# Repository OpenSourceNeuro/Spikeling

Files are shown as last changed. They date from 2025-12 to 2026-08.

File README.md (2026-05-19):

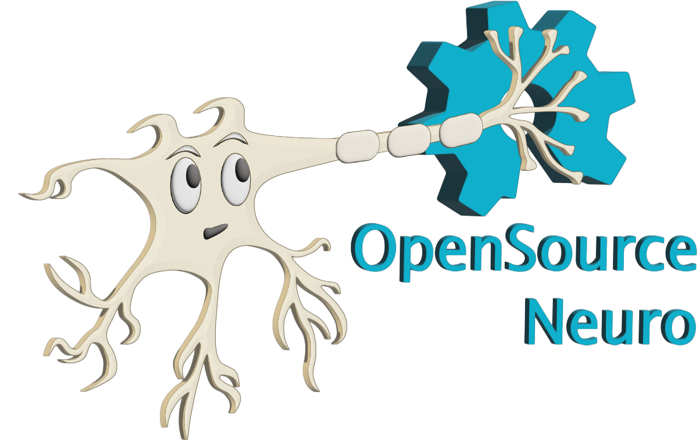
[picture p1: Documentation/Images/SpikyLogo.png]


<div align="center">

# **Spikeling v3**

### **An open-source hardware + software platform for neuroscience teaching and outreach:**  

A hands-on “artificial spiking neuron” running the **Izhikevich model** on an **ESP32**, with a desktop **GUI** for visualization, interaction, and data export.

<p>
  <a href="LICENSE.txt">
    
  </a>
  <a href="https://github.com/OpenSourceNeuro/Spikeling/releases">
    
  </a>
  <a href="https://opensourceneuro.github.io/Spikeling/Firmware/Spikeling_V3">
  
</a>
  <a href="https://opensourceneuro.github.io/Spikeling/">
    
  </a>
</p>

<p align="right">
  developed by M.J.Y. Zimmermann<br>
  maintained by P. Rignanese & A. Koumoundourou<br>
  based on an original idea by T. Baden
</p>

</div>

This project is licensed under the [GNU General Public License v3.0](https://www.gnu.org/licenses/gpl-3.0.en.html)
<br>
The hardware is licensed under the [ CERN-OHL-S-2.0](https://gitlab.com/ohwr/project/cernohl/-/wikis/uploads/b88fd806c337866bff655f2506f23d37/cern_ohl_s_v2_user_guide.txt)

## Contents

- [What is Spikeling?](#what-is-spikeling)
- [Spikeling in academia & outreach](#spikeling-in-academia--outreach)
- [A brief summary of Spikeling functions](#a-brief-summary-of-spikeling-functions)
  - [Neurophysiology](#neurophysiology)
  - [Data analysis](#data-analysis)
  - [Neuron generator](#neuron-generator)
  - [Stimulus generator](#stimulus-generator)
  - [Multi-recording & networking](#multi-recording--networking-multi-unit-experiments)
  - [Fluorescence imaging simulation](#fluorescence-imaging-simulation)
  - [Exercises](#exercises)
- [Documentation](#documentation)
- [Contributing](#contributing)
- [License](#license)

---

<br>

<div align="center">

## What is Spikeling?

<br>

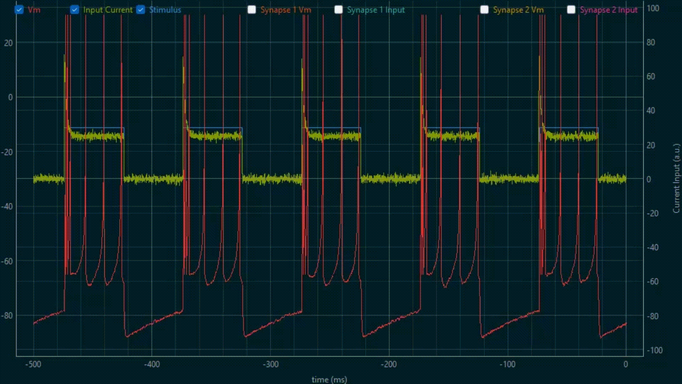
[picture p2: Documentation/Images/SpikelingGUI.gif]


<p style='text-align: justify;'>
  Spikeling is an open-source neuroscience education platform designed to make core neurophysiology concepts teachable through hands-on experimentation, even in settings where traditional wet-lab electrophysiology is impractical.
</p>

<p style='text-align: justify;'>
  In many degree programs, students learn about action potentials and synaptic signalling largely through lectures or static datasets because living preparations, microscopes, amplifiers, and specialist supervision do not scale well to large cohorts. Spikeling addresses this gap with a low-cost “in silico neuron” implemented in hardware.
</p>

<p style='text-align: justify;'>
  The device runs the computationally efficient and versatile <strong>Izhikevich spiking neuron model</strong> in real time on an ESP32-based microcontroller, providing electrophysiology-style interaction: controlled stimulation, measurable membrane-voltage dynamics, spike output, and parameter manipulation to explore firing regimes, adaptation, and input integration.
</p>

<p style='text-align: justify;'>
  A dedicated <strong>cross-platform desktop GUI</strong> supports real-time plotting, experiment control, and recording/export to standard formats—enabling teaching modules that extend beyond neurophysiology into protocol design, data collection, analysis pipelines, and model-based reasoning.
</p>

</div>

<br>

<div align="center">

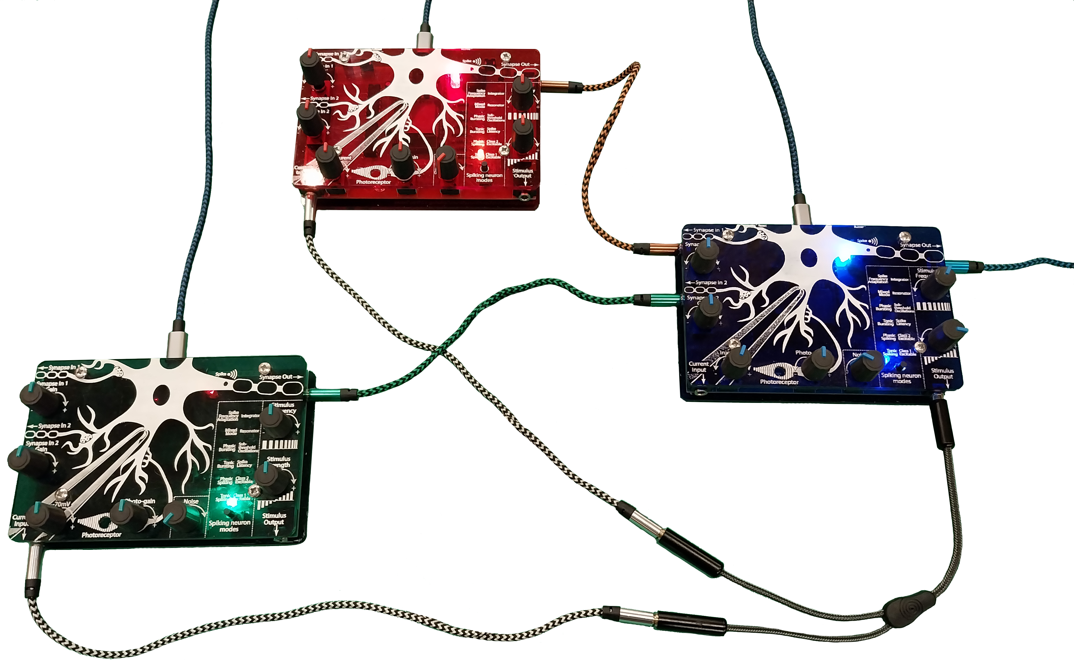
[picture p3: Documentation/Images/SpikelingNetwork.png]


<h6 align="center">Two spikeling units (red and green), that are synchronously stimulated (white cables), synapse with a third unit (blue).</h6>

</div>

---

<br>

<div align="center">

## Spikeling in academia & outreach

<br>

<p style='text-align: justify;'>
  The spikeling project emerged from local needs to teach neuroscience class modules for direct interaction with <strong>neuron physiology, data analysis, fluorescence imaging, protocol design, etc.</strong>
</p>

<p style='text-align: justify;'>
  The aim was to provide <strong>hands-on experience</strong> on how neurons encode information and how diverse variables modulates their activities, while engaging students with <strong>crucial aspects of data collection, experimental limitations, methodology and statistical analysis.</strong>
</p>

<p style='text-align: justify;'>
  Spikeling is currently used in <strong>university teaching, computational neuroscience training, and outreach events</strong>. It is intentionally <strong>open (hardware + firmware + software)</strong> so educators can customize activities for their courses and contribute back to a shared pool of teaching material.
</p>

<p align="center">
  Spikeling workshop — students using the device in South Africa (2022)
</p>

<table>
  <tr>
    <td width="33%">
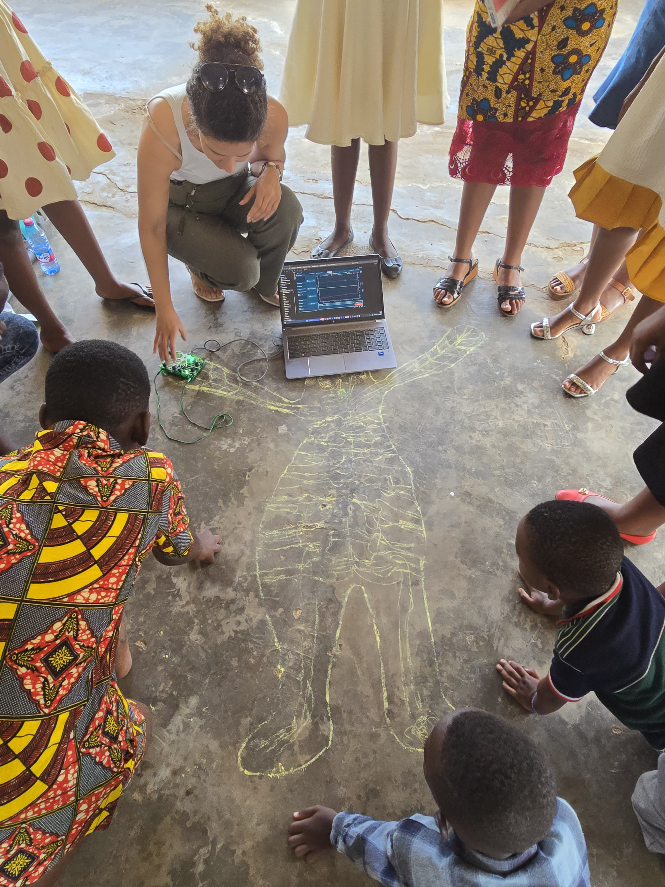
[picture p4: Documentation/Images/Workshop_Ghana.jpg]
      <br>
      <sub><b>Outreach demonstration of neuron activities to primary school student in Ghana (2025)</b></sub>
    </td>
    <td width="33%">
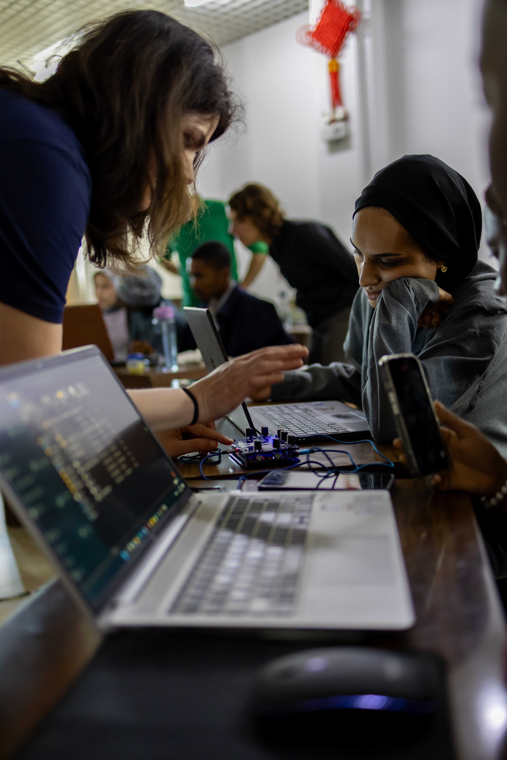
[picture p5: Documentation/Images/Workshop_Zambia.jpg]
      <br>
      <sub><b>Hands-on electrophysiology-style experiments in Zambia (2025)</b></sub>
    </td>
    <td width="33%">
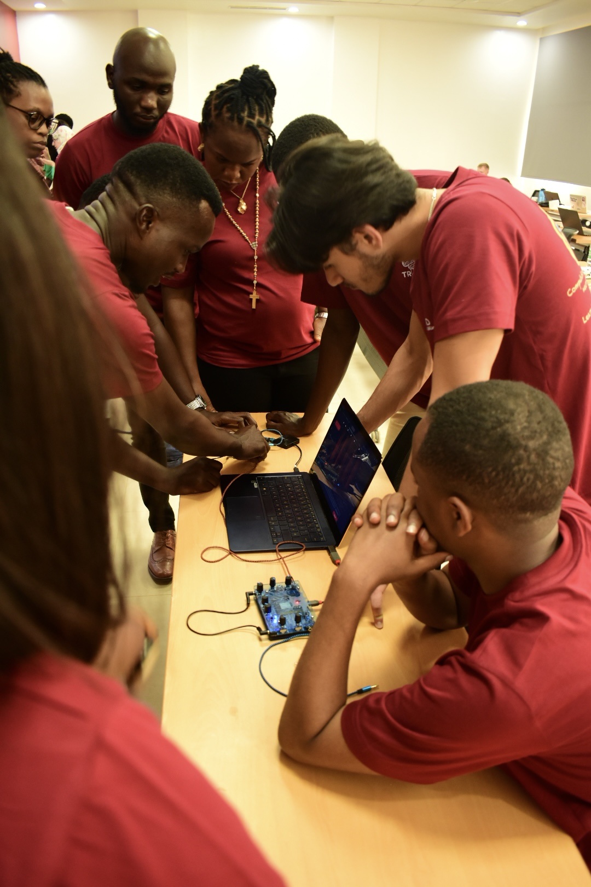
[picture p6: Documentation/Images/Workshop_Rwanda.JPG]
      <br>
      <sub><b>Small-group protocol design & parameter exploration in Rwanda (2024)</b></sub>
    </td>
  </tr>

</table>

</div>

***

<br>

<div align="center">

## A brief summary of Spikeling functions

<br>

<h3 align="left"> Neurophysiology:</h3></p>

<p style='text-align: justify;'>
  Spikeling implements the <strong>Izhikevich model</strong>, which “reproduces spiking and bursting behaviour of known type of cortical neurons. The model combines the <strong>biologically plausibility of Hodgkin-Huxley-type dynamics</strong> and the <strong>computational efficiency of integrate-and-fire neurons</strong>” <a href="https://ieeexplore.ieee.org/document/1257420"> E. M. Izhikevich, "Simple model of spiking neurons, 2003"</a>.
  This makes it well-suited for teaching as learners can move quickly between <strong>hypothesis → stimulation → observation → interpretation</strong>.
</p>

<p style='text-align: justify;'>
  Neurophysiology concepts are taught through electrophysiology-style interaction: students apply controlled inputs and directly observe membrane-voltage dynamics,
  thresholding, spike generation, and adaptation. This supports practical teaching objectives such as protocol design, parameter sensitivity, and reproducible experimentation.
</p>

<ul align="left">
  <li>
    <b>Patch-clamp style stimulation (current injection):</b>
    A simulated patch-clamp interface allows students to inject controlled current steps and waveforms.
    Learners can vary <b>amplitude</b>, <b>duration</b>, and <b>timing</b> to explore excitability, threshold, refractory effects, and spike-frequency adaptation.
  </li>

  <li>
    <b>Photo-sensitive input (photodiode / “photoreceptor”):</b>
    Spikeling includes a photodiode input that mimics sensory-driven current input.
    Students can test simple stimuli (e.g., flashlight pulses) and progress to controlled protocols using an external LED driven via the stimulus port
    (frequency/intensity). Advanced discussions can include response dynamics such as effective decay/recovery behaviour under repeated stimulation.
  </li>

  <li>
    <b>Synapses and networks (dendrites + axon):</b>
    Each unit provides <b>two dendritic inputs</b> with gain and polarity control (supporting excitatory and inhibitory effects) and <b>one axonal spike output</b>.
    This enables multi-unit experiments on coincidence detection, inhibition-driven gating, synchrony, and simple network motifs.
    Auxiliary units can be stimulated synchronously to keep network experiments controlled and reproducible.
  </li>
</ul>

<p style='text-align: justify;'>
  Together, these features let students reproduce classic teaching experiments:
  step-current response curves, threshold measurements, adaptation quantification, sensory-driven spiking, and basic synaptic/network computations—using the same device and workflow.
</p>

<br>

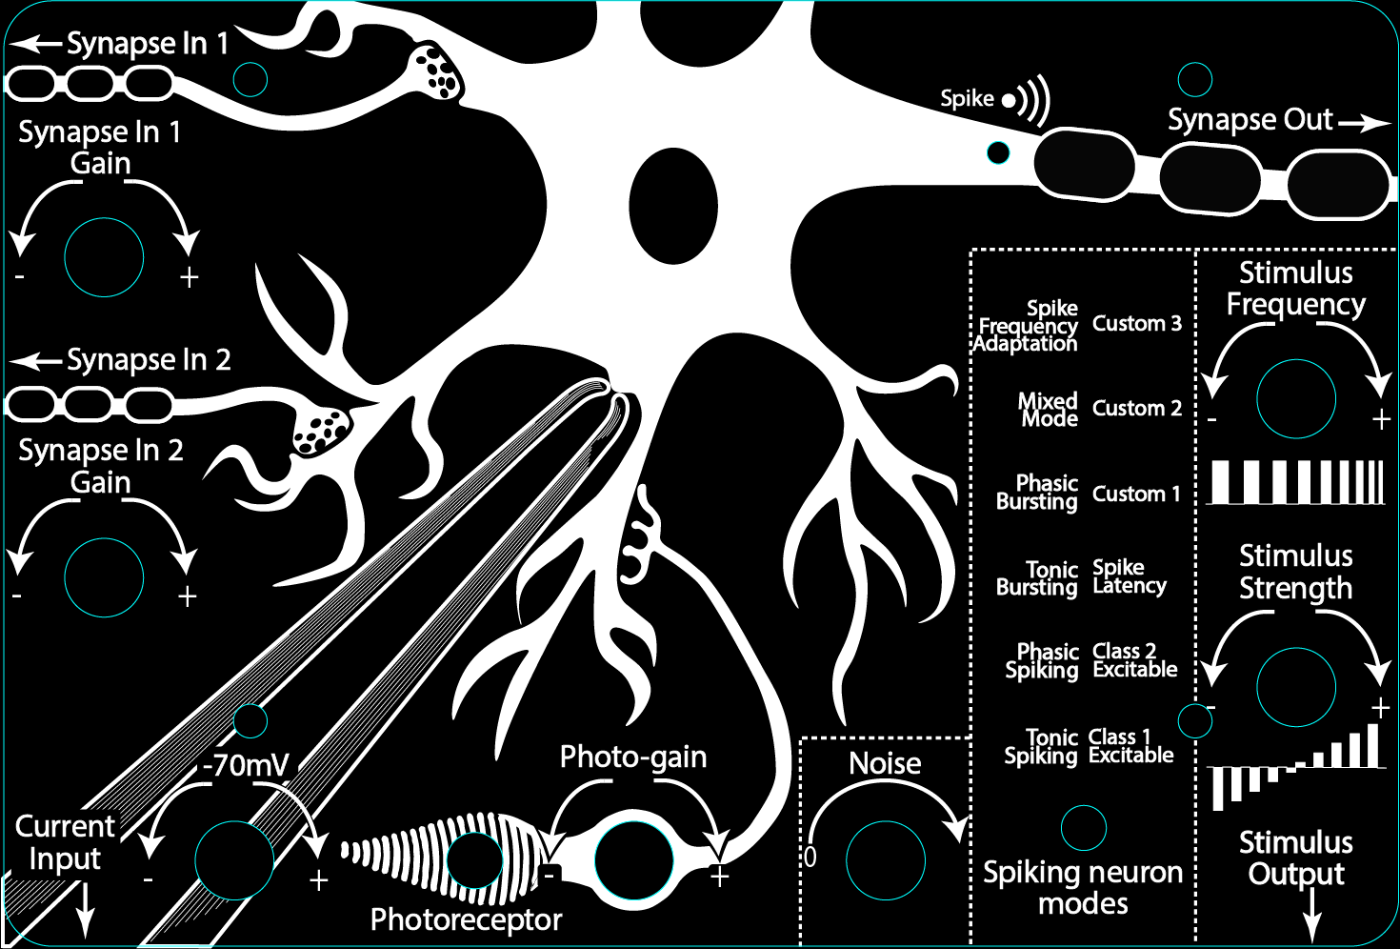
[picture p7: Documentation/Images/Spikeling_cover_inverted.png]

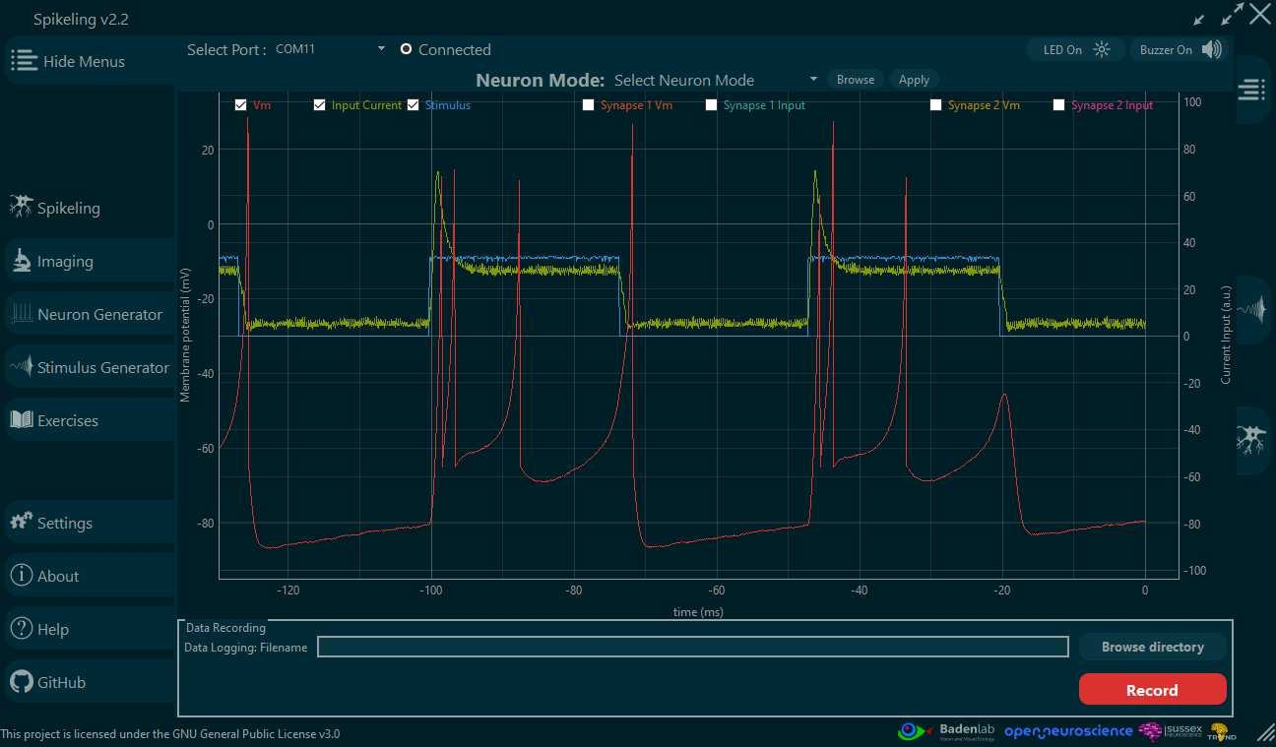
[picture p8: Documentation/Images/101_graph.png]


<h6 align="center">Left: Drawing on the acrylic cover of the Spikeling version 2.2, representing the controls knobs along with the input/ouput jacks.

Right: Spikeling GUI displaying the unit membrane voltage (red trace) while being light-stimulated by a controlled LED (blue trace) which generates input current (green trace).
</h6>

</div>

***

<div align="center">

<h3 align="left"> Data analysis</h3></p>

<p style='text-align: justify;'>
  Spikeling is designed to extend practical teaching beyond “watching spikes” into the full experimental workflow:
  <strong>recording</strong>, <strong>quality control</strong>, <strong>basic quantification</strong>, and <strong>export for reproducible analysis</strong>.
  This is particularly valuable in neuroscience curricula where students may have limited exposure to programming and data pipelines, yet are expected to interpret real experimental data.
</p>

<p style='text-align: justify;'>
Any data generated by Spikeling can be <strong>saved and exported</strong> for downstream analysis. The GUI also provides a lightweight,
<strong>built-in analysis</strong> layer that helps students validate recordings and immediately compute core measures such as spike detection and trial-averaged responses.
This supports in-class demonstrations, rapid iteration during labs, and structured home assignments.
</p>

<p style='text-align: justify;'>
  For advanced data analysis and basic statistics, <strong>python notebooks</strong> are provided to serve as template for the teaching staff. We are engage with the Spikeling community where users could share courses, exercises and data analysis scripts to be widely used in neuroscience and coding courses.
</p>

<ul align="left">
  <li>
    <b>Recording & export:</b>
    save time series (e.g., Vm, stimulus, derived currents, triggers) and export to standard formats (e.g., <b>CSV</b>) compatible with Python, MATLAB, R, Excel, etc.
  </li>
  <li>
    <b>Basic QC and annotation:</b>
    quickly verify signal integrity, confirm stimulus timing, and identify artefacts before committing to a full analysis workflow.
  </li>
  <li>
    <b>Spike detection and raster plots:</b>
    detect spikes from membrane-voltage traces and visualize them as rasters to introduce spike trains, variability, and stimulus-locked responses.
  </li>
  <li>
    <b>Trial alignment, looping, and averaging:</b>
    repeat identical stimulus protocols, align trials, and compute averaged traces and spike-rate summaries—making it easy to teach concepts like reliability,
    response variability, and signal-to-noise.
  </li>
  <li>
    <b>Bridge to coding modules:</b>
    provide exported datasets and template <b>Python notebooks</b> so teaching staff can scaffold progressively from GUI-based inspection to student-written analysis code.
  </li>
</ul>

<p style='text-align: justify;'>
  In short, Spikeling supports a gradual learning curve: students can begin with GUI-based inspection and built-in metrics,
  then transition to reproducible, script-based analysis using the exact same datasets—mirroring modern research practice.
</p>
<br>

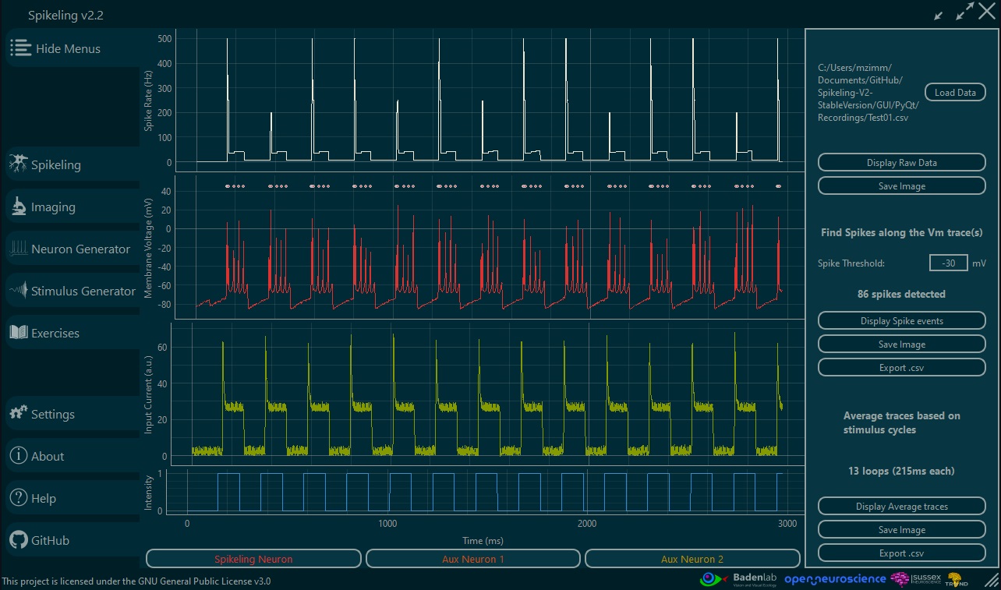
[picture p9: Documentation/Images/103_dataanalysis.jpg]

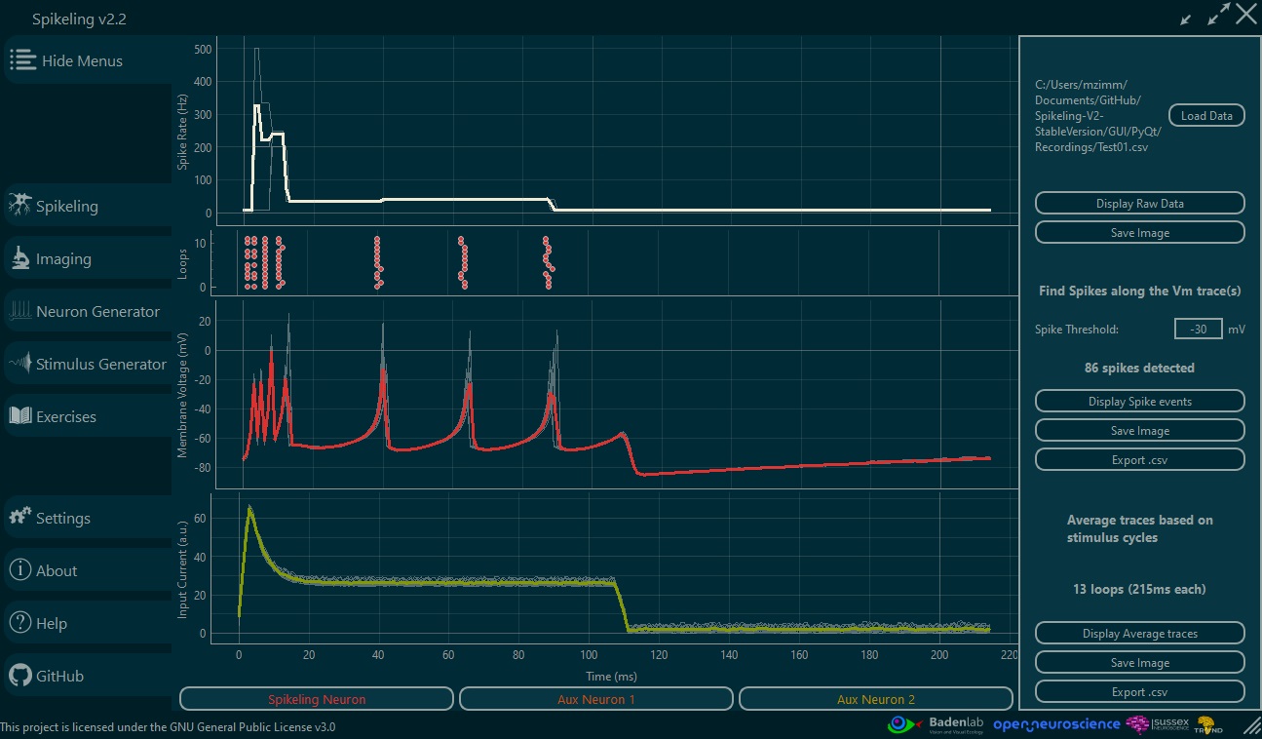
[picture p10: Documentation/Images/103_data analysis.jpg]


<h6 align="center">Left: Displayed data from the previous experiment (light stimulation) spikes are detected and ploted along the Vm trace (red). Right: Traces looped and averaged showing the spike rate (white), the raster plot (red dots), the averaged Vm recording (red) and the averaged input current (green)</h6>

</div>

***

<div align="center">

<h3 align="left"> Neuron generator</h3></p>

<p style='text-align: justify;'>
  The <strong>Neuron Generator</strong> is an interactive space for exploring the Izhikevich model beyond “playing with a few knobs”.
  It is designed to help students connect <strong>model parameters</strong> to <strong>observable firing behaviours</strong> (e.g., tonic spiking, bursting, adaptation, rebound, irregular firing),
  and to build intuition for how different neurons can emerge from the same compact set of equations.
</p>

<p style='text-align: justify;'>
  In practice, the Neuron Generator lets learners rapidly prototype neuron “types” by adjusting Izhikevich parameters and immediately observing
  how the neuron responds to standardized stimuli. This encourages a scientific workflow: formulate a hypothesis (e.g., “increasing adaptation should reduce firing rate over time”),
  test it with controlled stimulation, then iterate.
</p>

<ul align="left">
  <li><b>Explore firing regimes:</b> interactively vary Izhikevich parameters and observe changes in excitability, thresholding, bursting, and adaptation.</li>
  <li><b>Compare neurons under identical protocols:</b> run the same stimulus recipe on multiple parameter sets to build mechanistic intuition.</li>
  <li><b>Create & share presets:</b> save custom neuron parameter sets for labs, assignments, or reproducible classroom demonstrations.</li>
  <li><b>Bridge theory and experiment:</b> connect equations/parameters to patch-clamp-style readouts (Vm traces, spike trains, firing-rate changes).</li>
</ul>

<br>

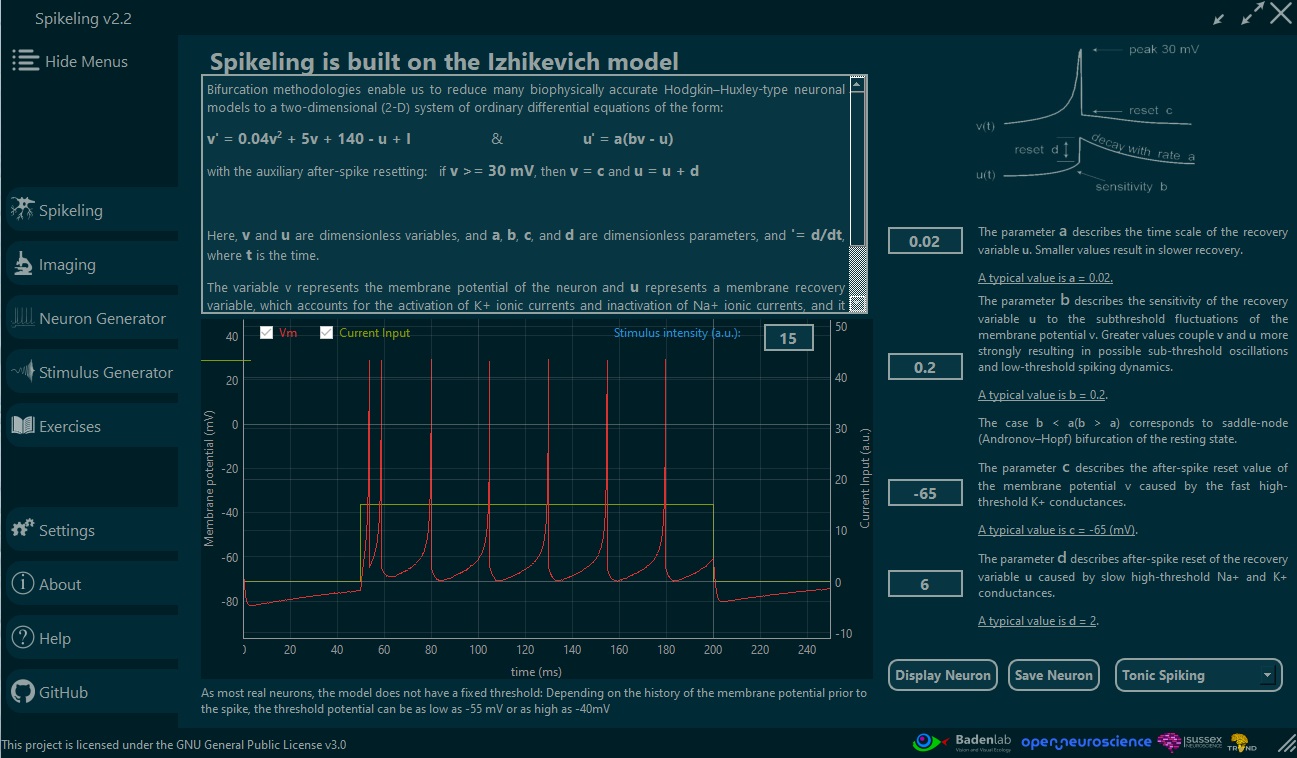
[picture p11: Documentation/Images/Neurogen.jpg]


<h6 align="center">GUI displaying the “Neuron Generator” page where users can appreciate the model underlying Spikeling activity and from which they can generate unique neuron to further run on Spikeling.</h6>

</div>

***

<div align="center">

<h3 align="left">Stimulus generator:</h3>

<p style='text-align: justify;'>
  Spikeling includes a dedicated <strong>Stimulus Generator</strong> to teach one of the most important (and often under-taught) parts of experimental neuroscience:
  <strong>protocol design</strong>. While Spikeling board only has a simple repeated square-wave stimulus (useful for classic current-step experiments and LED/light stimulation),
  the Stimulus Generator encourages students to move beyond “turning knobs” and instead design inputs that directly test experimental hypotheses.
</p>

<p style='text-align: justify;'>
  Users can create and iterate custom stimuli—such as <strong>step families</strong>, <strong>sinusoids</strong>, <strong>chirps</strong>, <strong>pulse trains</strong>, and <strong>binary/noise-like</strong> sequences—
  then apply them to current injection or light stimulation. A built-in <strong>stimulus preview</strong> allows learners to verify waveform timing, amplitude, and repetition structure
  <em>before</em> running an experiment, reinforcing good practice around sanity checks and reproducibility.
</p>

<ul align="left">
  <li><b>From standard to custom protocols:</b> start with square pulses and progress to structured waveforms used in electrophysiology and systems neuroscience.</li>
  <li><b>Preview before running:</b> confirm duration, inter-stimulus intervals, amplitude scaling, and repetition count to avoid protocol errors.</li>
  <li><b>Reproducible experimentation:</b> define explicit parameters to enable trial averaging and fair comparisons across neuron modes or conditions.</li>
  <li><b>Hypothesis-driven design:</b> link stimulus structure to questions like threshold, adaptation time constants, resonance, and response reliability under noise.</li>
</ul>

<br>

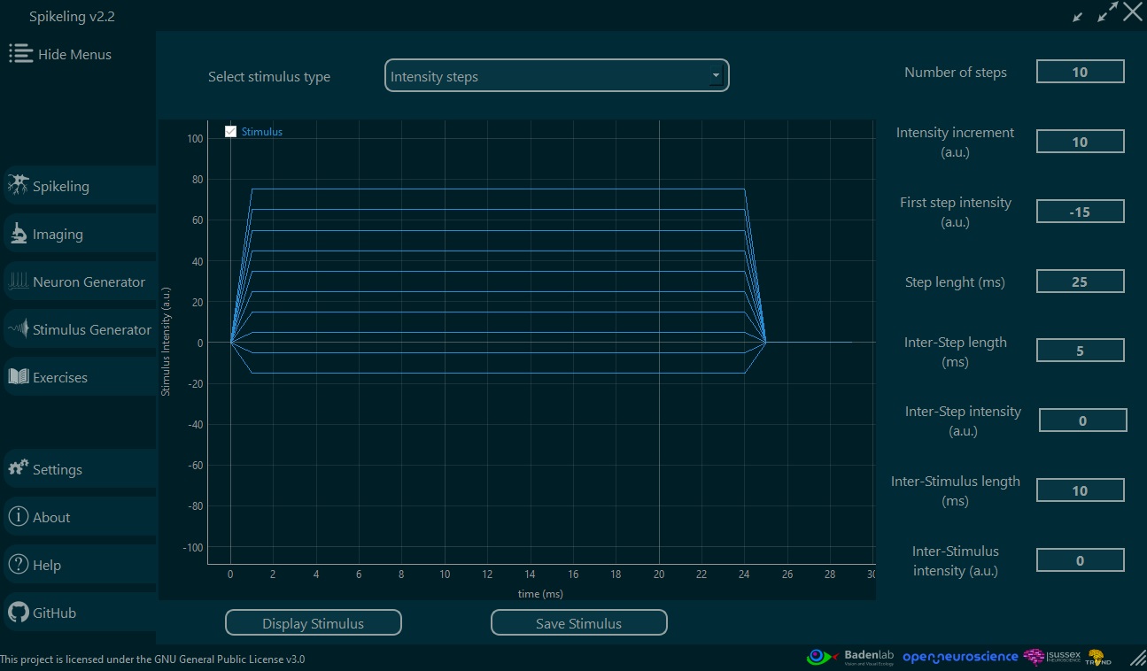
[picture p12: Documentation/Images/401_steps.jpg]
  
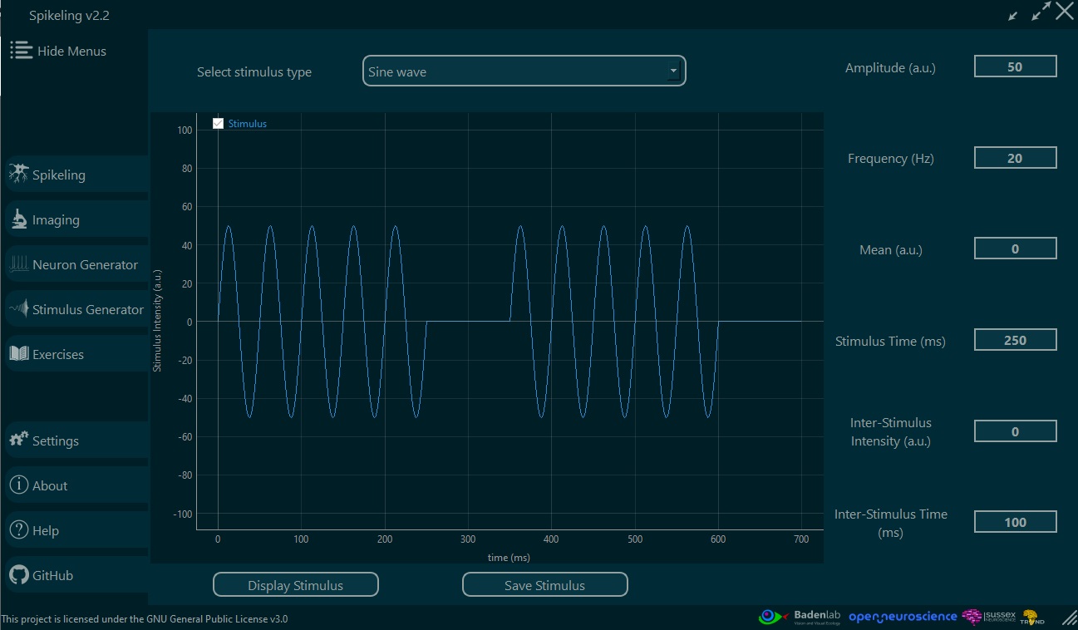
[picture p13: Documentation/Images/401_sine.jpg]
  

  <h6 align="center">
    Stimulus Generator examples (with preview). Left: classic electrophysiology-style step family (10 steps, 10 a.u. increment, 25 ms per step, 5 ms rest at 0 a.u.).
    Right: sine-wave stimulus (50 a.u. amplitude, 20 Hz, 250 ms duration, 100 ms rest at 0 a.u.).
  </h6>

</div>

***

<div align="center">

<h3 align="left">Multi-recording & networking (multi-unit experiments):</h3>

<p style='text-align: justify;'>
  A key strength of Spikeling is that it can be scaled from a single “neuron” demo to <strong>small, interpretable networks</strong>.
  Each unit provides an <strong>axonal spike output</strong> and two <strong>dendritic (synaptic) inputs</strong>, enabling multiple Spikelings to be physically connected
  and studied as a functional circuit. This makes it possible to teach network-level computation using the same workflow as single-cell experiments:
  controlled stimulation, direct observation, and quantitative comparison.
</p>

<p style='text-align: justify;'>
  Importantly, each synaptic input can be configured as <strong>excitatory or inhibitory</strong> (via the synaptic gain control), allowing learners to explore
  how the <strong>sign</strong> and <strong>strength</strong> of coupling shapes membrane dynamics and spiking output. The GUI supports <strong>multi-recording</strong> by plotting and saving,
  in the same session, the activity of the main unit alongside the incoming synaptic streams (and, when available, the associated presynaptic signals),
  which is essential for teaching causality, timing, and interaction effects.
</p>

<ul align="left">
  <li><b>Excitation vs inhibition:</b> set synaptic gain positive or negative to illustrate recruitment of spiking vs suppression/gating.</li>
  <li><b>Timing-dependent effects:</b> compare synchronous vs offset inputs to demonstrate coincidence detection and integration windows.</li>
  <li><b>Simple circuit motifs:</b> build and test canonical motifs (feedforward excitation, inhibitory gating, E/I balance, two-input integration).</li>
  <li><b>Multi-channel recording:</b> visualize and export multiple traces simultaneously (main Vm, stimulus, synaptic inputs, and optional partner activity) for downstream analysis.</li>
</ul>

<br>

<div>
  <!-- Rename/move these screenshots into your repo (recommended location: ./Documentation/Images/ ) -->
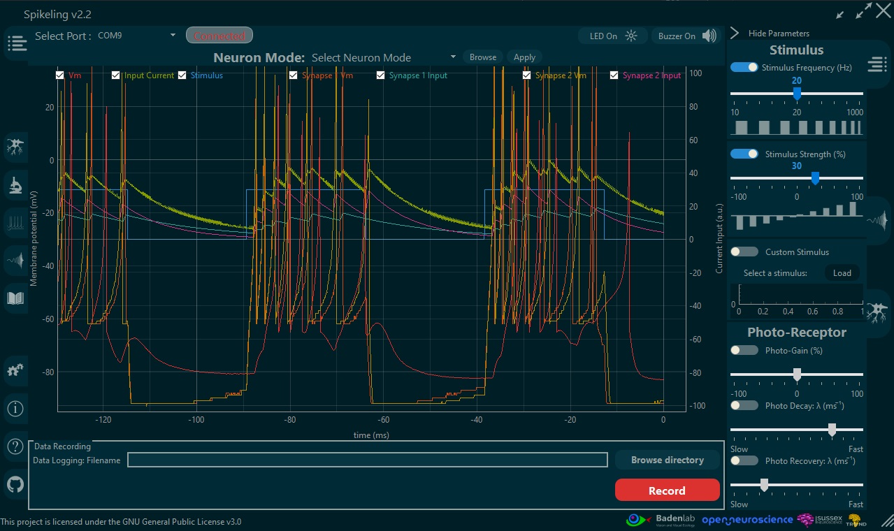
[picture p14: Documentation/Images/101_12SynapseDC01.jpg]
  
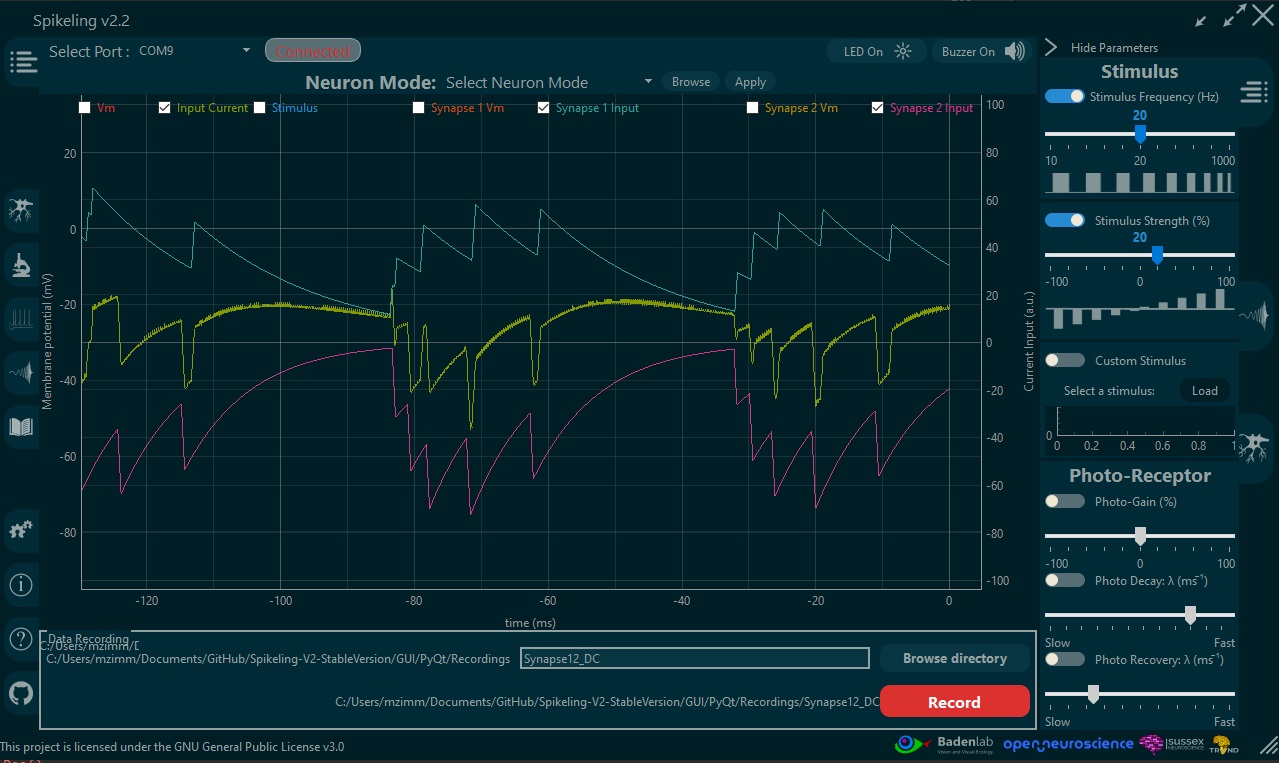
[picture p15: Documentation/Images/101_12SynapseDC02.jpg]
  

  <h6 align="center">
    Multi-unit / synaptic networking example recorded in the GUI.
    Left: <b>excitatory</b> synaptic drive increases firing probability and can recruit spikes in the postsynaptic neuron.
    Right: <b>inhibitory</b> synaptic drive suppresses spiking and gates responses despite ongoing stimulation.
    In both cases, synaptic streams and membrane activity are visualised together, enabling direct comparison of circuit configurations.
  </h6>

</div>

---

<div align="center">

<h3 align="left">Fluorescence imaging simulation:</h3>

<p style='text-align: justify;'>
  Because Spikeling produces real-time <strong>membrane-voltage</strong> traces (and therefore a known spike train), it provides an ideal “ground truth” signal
  to introduce students to <strong>calcium imaging</strong> and the relationship between spikes, intracellular calcium dynamics, and measured fluorescence.
  The GUI can transform spiking activity into a simulated <strong>calcium concentration transient</strong>, and then into a simulated <strong>fluorescence signal</strong>,
  allowing learners to explore how imaging readouts relate to the underlying electrophysiology.
</p>

<p style='text-align: justify;'>
  Students can manipulate variables that mirror real experimental constraints—both on the acquisition side (e.g., <strong>frame rate</strong>, <strong>detector gain</strong>, <strong>noise level</strong>)
  and on the biophysical/indicator side (e.g., <strong>baseline calcium</strong>, <strong>decay time constant</strong>, <strong>spike-triggered calcium increment</strong>,
  <strong>indicator affinity / dissociation constant</strong>, <strong>brightness</strong>, and <strong>photobleaching-like effects</strong>).
  This helps learners understand why calcium traces are not a direct copy of spikes, and why interpretation depends on both biology and measurement.
</p>

<p style='text-align: justify;'>
  For increased realism, the simulation can be switched from a <strong>linear</strong> fluorescence model to a <strong>non-linear saturating</strong> model,
  illustrating common limitations such as dynamic range, saturation at high activity, and the consequences for comparing firing rates across conditions.
</p>

<br>

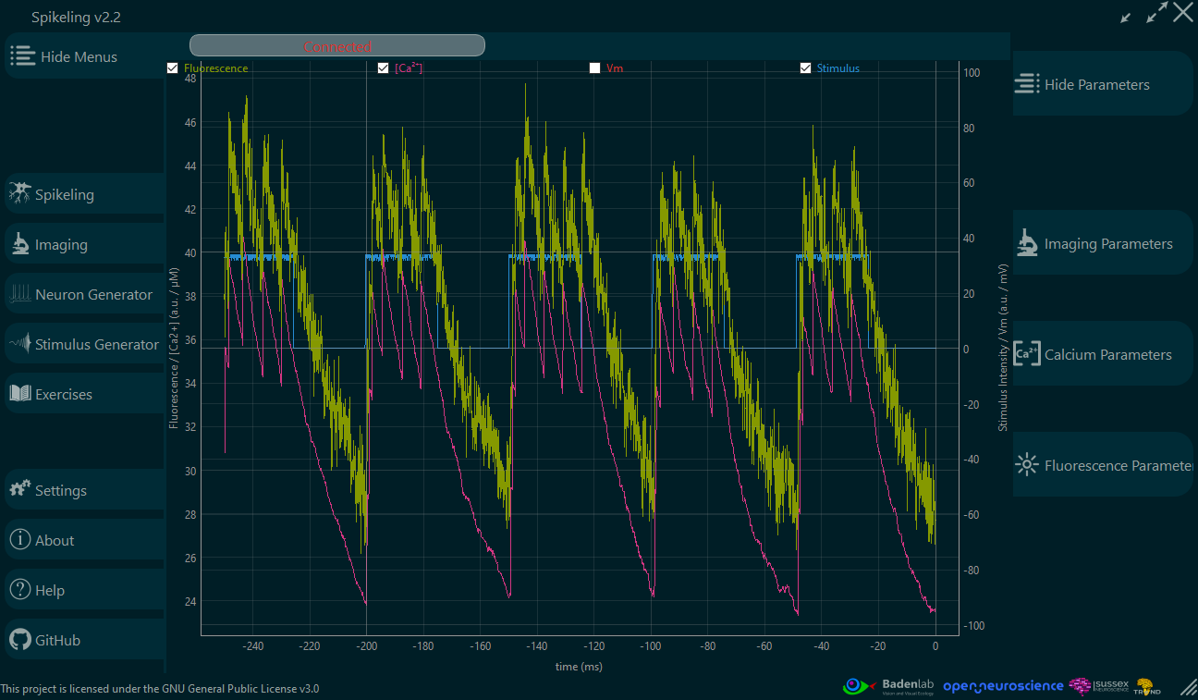
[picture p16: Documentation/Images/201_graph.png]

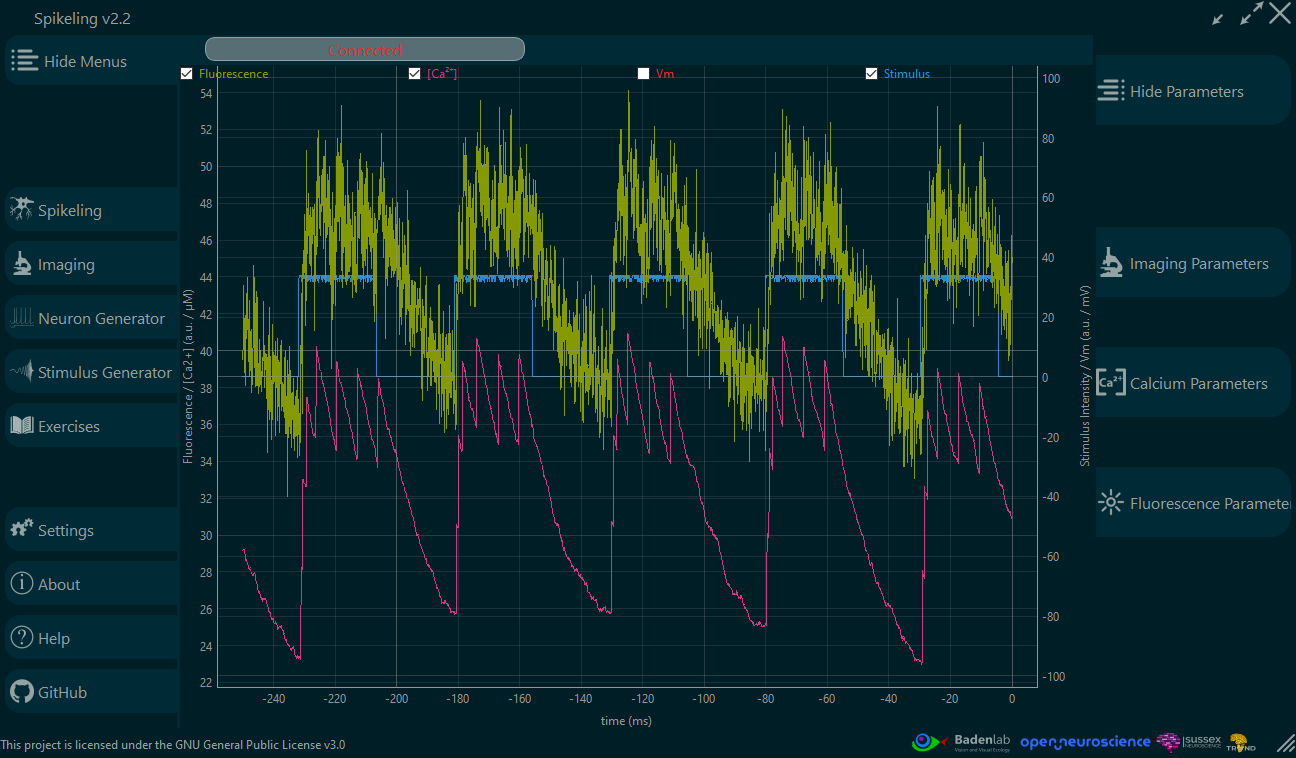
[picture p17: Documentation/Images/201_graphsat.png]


<h6 align="center">
  Imaging simulation in the GUI: linear (left) and saturating / non-linear (right) fluorescence models (green) generated from simulated calcium concentration dynamics (pink).
</h6>

<p style='text-align: justify;'>
  The objective is to familiarise students with the type of data they will encounter in modern systems and circuit neuroscience:
  signals that are <strong>indirect</strong>, <strong>noisy</strong>, and shaped by both the underlying biology and the measurement apparatus.
  This creates a natural pathway to discussing experimental limitations (sampling, noise, saturation, bleaching) and good analysis practice.
</p>

<p style='text-align: justify;'>
  In advanced modules, students can analyse the simulated imaging data and implement <strong>spike inference</strong> methods, then directly compare inferred spikes
  to the known “ground truth” spike train that generated the fluorescence trace—turning a common challenge in imaging into a controlled, teachable problem.
</p>

</div>

***

<div align="center">

<h3 align="left">Exercises:</h3>

<p style='text-align: justify;'>
  Spikeling is accompanied by a set of <strong>suggested exercises</strong> designed to help teaching staff run structured practicals with minimal setup.
  The exercises are intended to create a concrete bridge between core neurophysiology concepts taught in lectures and a responsive, real-time <strong>in silico</strong> neuron model
  that students can stimulate, measure, and analyse.
</p>

<p style='text-align: justify;'>
  Beyond technical skills, the exercises are also a vehicle for introducing scientific reasoning and epistemology:
  how a concept becomes knowledge, what it means to test a hypothesis, and how results can <strong>support, constrain, or falsify</strong> an interpretation.
  In advanced modules, students can be asked to design their own experiment as an assignment—emphasising good practice in <strong>methodology</strong> and <strong>protocol design</strong>
  (controls, parameter choices, repeatability, and appropriate analysis), rather than treating “methods” as a checklist.
</p>

<ul align="left">
  <li><b>Ready-to-run practicals:</b> structured activities covering excitability, threshold, adaptation, synaptic integration, and basic networks.</li>
  <li><b>Analysis-focused assignments:</b> exported datasets for plotting, spike detection, summary metrics, and interpretation.</li>
  <li><b>Open-ended projects:</b> student-designed stimuli and protocols to answer a defined question (with clear evaluation criteria).</li>
</ul>

<p style='text-align: justify;'>
  We encourage educators to adapt and extend these exercises to match their curricula. Our goal is to grow a shared pool of teaching material where users can contribute
  new exercises, datasets, and analysis notebooks—making Spikeling progressively more useful across institutions and course formats.
</p>

</div>

---

## Documentation

<div align="left">
The full documentation is hosted as a project wiki and is the recommended entry point for educators and new users.

It covers:
- **Getting started** (hardware overview, connections, first experiment)
- **Firmware** (flashing, configuration, serial protocol)
- **GUI user guide** (controls, plotting, recording/export, troubleshooting)
- **Teaching materials** (suggested lab exercises, workflows, assignments)
- **Advanced modules** (synapses/networks, stimulus design, fluorescence imaging simulation, emulator mode)

**Docs website:** https://opensourceneuro.github.io/Spikeling/  
**Firmware documentation:** https://opensourceneuro.github.io/Spikeling/Firmware/Spikeling_V3  
**Releases (pre-built GUI):** https://github.com/OpenSourceNeuro/Spikeling/releases

---

## Contributing

Spikeling is an open hardware + open software teaching platform. Contributions are welcome across **hardware**, **firmware**, **GUI/software**, **documentation**, and **teaching materials**.

### How to contribute
- **Report bugs / request features:** open an issue  
  https://github.com/OpenSourceNeuro/Spikeling/issues
- **Submit improvements:** open a pull request  
  https://github.com/OpenSourceNeuro/Spikeling/pulls
- **Share teaching content:** contribute new exercises, worksheets, datasets, and analysis notebooks (with learning goals and expected outcomes) so other instructors can reuse them.

### What to include in an issue (so we can reproduce it)
- your OS (Windows/macOS/Linux) + Spikeling GUI version
- firmware version (and board revision if known)
- clear steps to reproduce + what you expected vs what happened
- screenshots/logs and (when relevant) a short exported CSV

### Pull request guidelines (practical and lightweight)
- Keep PRs focused (one improvement per PR when possible).
- Follow existing style and folder structure.
- For GUI changes: include a screenshot/GIF and note any new dependencies.
- For firmware changes: document parameters/commands and keep backward compatibility when reasonable.
- For docs/exercises: include learning objectives, required materials, and approximate duration.

### Community and attribution
Spikeling is used in teaching and outreach worldwide. If you adapt it for a course, workshop, or public event, please consider contributing back:
- photos (with permission), module outlines, and lab handouts
- custom neuron presets and stimulus protocols
- analysis notebooks and grading rubrics

All contributors will be acknowledged via GitHub history, and substantial contributions can be credited in documentation and release notes.

---

## License

Spikeling is released under **open-source / open-hardware** licenses:

- **Software & firmware:** **GNU General Public License v3.0** (GPL-3.0)  
  See `LICENSE.txt` (and individual file headers where applicable).

- **Hardware:** **CERN Open Hardware Licence – Strongly Reciprocal v2.0** (**CERN-OHL-S-2.0**)  
  See the `LICENSES/` folder for the full text and attribution of hardware design files.

If you reuse Spikeling in a course, workshop, publication, or derivative project, please keep the appropriate license notices and cite the project where relevant.

</div>

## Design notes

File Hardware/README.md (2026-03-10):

<p align="left">
  Spikeling logo
</p>

<div align="center">

# **Hardware design, assembly, and revision notes**

<p>
  <a href="../LICENSES/CERN-OHL-S-2.0.txt">
    
  </a>
  <a href="https://opensourceneuro.github.io/Spikeling/hardware/">
    
  </a>
  <a href="https://opensourceneuro.github.io/Spikeling/reference/pinout-and-connectors/">
    
  </a>
  <a href="https://opensourceneuro.github.io/Spikeling/reference/specs/">
    
  </a>
</p>

</div>

This folder contains the hardware side of **Spikeling**: board revisions, build notes, connector conventions, and practical guidance for bringing a unit from PCB to a working neuroscience teaching device.

Spikeling is an open hardware + software platform for hands-on neuroscience teaching and outreach. It exposes a spiking neuron model through real controls, real I/O, and real-time visualisation, allowing students to run electrophysiology-style experiments without a full wet-lab rig.

**Quick links**
- [Main repository](../)
- [Firmware folder](../Firmware)
- [Software folder](../Software)
- [Documentation folder](../Documentation)
- [Hardware documentation](https://opensourceneuro.github.io/Spikeling/hardware/)
- [Quickstart: hardware setup](https://opensourceneuro.github.io/Spikeling/quickstart/hardware-setup/)
- [Reference: pinout and connectors](https://opensourceneuro.github.io/Spikeling/reference/pinout-and-connectors/)
- [Reference: specs](https://opensourceneuro.github.io/Spikeling/reference/specs/)

<p align="right">
  developed by M.J.Y. Zimmermann<br>
  maintained by P. Rignanese & A. Koumoundourou<br>
  based on an original idea by T. Baden
</p>

---

## **1. What this folder is for**

Use the `Hardware` folder as the entry point for:

- PCB design files and revision history
- manufacturing outputs and sourcing material
- assembly notes and bring-up checks
- connector / wiring conventions
- calibration and troubleshooting notes
- hardware differences between Spikeling generations

This README is meant to help contributors, builders, and teaching staff quickly understand which board they have, how it differs from other revisions, and where to find the next level of detail.

---

## **2. Hardware families**

Spikeling currently exists in two official board families.

### **Spikeling v2.x**
- **Microcontroller:** ESP32 WROOM-32
- **USB connector:** mini-USB
- **USB behaviour:** USB-to-UART bridge (**CP210x**)
- **Driver requirement:** often required, especially on Windows
- **Neuron mode selection:** on-board **Mode** button
- **Preset neuron modes:** 12

### **Spikeling v3.x**
- **Microcontroller:** ESP32-S3 WROOM-1
- **USB connector:** USB-C
- **USB behaviour:** native USB (**USB CDC serial**)
- **Driver requirement:** typically no separate USB-UART driver required
- **Neuron mode selection:** from the **GUI**
- **Preset neuron modes:** 20
- **Additional hardware compared to v2.x:** external DAC IC
- **Additional convenience features:** LiPo power-control hardware and a dedicated control to disable the Vm LED

> In practice, both families support the same teaching workflow: stimulate the model neuron, observe Vm and spikes, connect units together, and record/export data. The main differences affect USB connection, firmware target, mode selection, and a few hardware conveniences.

---

## **3. Version 2 vs version 3 — practical differences**

### **Connection and setup**
- **v2.x** uses a CP210x USB-to-UART bridge, so serial detection depends on that driver being installed.
- **v3.x** uses the ESP32-S3 native USB interface and usually enumerates directly as a USB serial device.

### **User interaction**
- **v2.x** changes neuron behaviour using an on-board **Mode** button.
- **v3.x** moves neuron mode selection into the GUI, which makes classroom switching and software-driven workflows more convenient.

### **Analogue output hardware**
- **v3.x** adds an external DAC compared with **v2.x**, improving the hardware architecture for the newer board generation.

### **Power and convenience controls**
- **v3.x** adds hardware support for the LiPo extension and includes a control to disable the Vm LED.
- **v2.x** is the simpler earlier platform and is closer to the minimal USB-to-ESP32 teaching-board architecture.

### **How to identify them quickly**
- **mini-USB = v2.x**
- **USB-C = v3.x**

---

## **4. What Spikeling hardware does**

At the hardware level, Spikeling behaves like a compact teaching-oriented electrophysiology preparation:

- multiple input pathways contribute to the neuron’s total drive
- the board exposes a measurable membrane potential (**Vm**)
- threshold crossings generate discrete spike events
- the board streams signals to the desktop GUI for visualisation, stimulation, and recording

### **Main input pathways**
- current injection control
- on-board square-wave stimulus generator
- GUI-driven stimulus generator
- photodiode input for light stimulation
- Synapse 1 / Synapse 2 inputs from other Spikeling units

### **Main outputs**
- analogue **Vm**
- digital spike events
- stimulus output for external use
- real-time USB serial stream to the GUI

---

## **5. Controls and I/O philosophy**

Spikeling uses **3.5 mm stereo TRS jacks** to carry both analogue and digital signals with a shared ground.

### **TRS convention**
- **Tip (T)** = digital / TTL
- **Ring (R)** = analogue signal
- **Sleeve (S)** = ground

This makes the hardware compact and classroom-friendly: one cable can carry both a continuously varying signal and an event marker.

### **Typical signal roles**
- **Synaptic / axon output:** analogue = presynaptic Vm, digital = spike events
- **Stimulus output:** analogue = stimulus waveform, digital = PWM / timing signal
- **Synapse input 1 / 2:** receives a TRS feed from another unit
- **Current input:** receives an injected analogue waveform
- **Photodiode workflow:** an LED driven through the stimulus path can act as a controlled light stimulus

### **Common wiring patterns**
- **Axon output (unit A) → Synapse input (unit B)** for two-unit network experiments
- **Stimulus output → LED cable → photodiode** for controlled light stimulation
- **Stimulus output → current input** for waveform-based injected current experiments

> Ground continuity matters. Many noisy or unstable measurements are caused by missing or inconsistent ground reference on the TRS sleeve.

---

## **6. Core teaching-facing controls**

The exact silkscreen may vary slightly between revisions, but the core controls remain conceptually stable.

- **Current injection**: direct depolarising / hyperpolarising drive
- **Stimulus strength**: amplitude of the on-board square-wave drive
- **Stimulus frequency**: repetition rate of the on-board stimulus
- **Noise**: Gaussian noise added to the input drive
- **Photo gain (±)**: gain and polarity of the photodiode input
- **Synapse 1 gain (±)**: excitatory or inhibitory strength of synapse 1
- **Synapse 2 gain (±)**: excitatory or inhibitory strength of synapse 2
- **Reset**: return the board to a known state
- **Buzzer mute**: disable spike audio feedback

### **Revision-specific controls**
- **v2.x:** Mode button selects one of 12 preset Izhikevich parameter sets
- **v3.x:** neuron mode is selected in the GUI, and the board adds:
  - **Vm LED disable**
  - **LiPo power switch / power-control hardware**

---

## **7. Minimum hardware needed to use a board**

### **For either generation**
- one Spikeling unit
- one data-capable USB cable
- at least one **3.5 mm TRS stereo cable**
- a computer running the GUI
- optionally, an LED stimulus cable for photodiode experiments

### **Board-specific USB cables**
- **v2.x:** mini-USB data cable
- **v3.x:** USB-C data cable

### **Recommended extras**
- powered USB hub
- spare TRS patch cables
- TRS-to-breakout adapter(s)
- multimeter
- optional oscilloscope or logic analyser for debugging

---

## **8. Quick bring-up checklist**

Before troubleshooting firmware or GUI issues, confirm the physical layer first.

- I know whether the board is **v2.x** or **v3.x**
- I am using a **data-capable** USB cable
- The board appears as a serial device on the computer
- For **v2.x**, the **CP210x** driver is installed
- I have at least one known-good **TRS** cable
- I understand the **Tip / Ring / Sleeve** mapping
- No other application is already holding the serial port
- The board can be reset cleanly and reconnects

---

## **9. Recommended workflow**

### **If you are using an already-built board**
1. Identify the board family (**v2.x** or **v3.x**)
2. Connect USB and confirm the serial port appears
3. Install / launch the GUI
4. Flash the correct firmware if needed
5. Run a simple current injection or stimulus protocol
6. Add TRS cabling for synapse or photodiode experiments

### **If you are assembling hardware**
1. Start from the correct board revision
2. Follow a disciplined soldering order
3. Inspect for shorts, polarity mistakes, and connector orientation
4. Bring the board up with USB only before adding more hardware
5. Verify serial enumeration
6. Verify basic stimulus / Vm / spike behaviour before multi-unit experiments

---

## **10. Documentation map**

### **Hardware**
- [Hardware overview](https://opensourceneuro.github.io/Spikeling/hardware/)
- [Bill of materials](https://opensourceneuro.github.io/Spikeling/hardware/bom/)
- [Assembly](https://opensourceneuro.github.io/Spikeling/hardware/assembly/)
- [Calibration](https://opensourceneuro.github.io/Spikeling/hardware/calibration/)
- [Mechanical mounting](https://opensourceneuro.github.io/Spikeling/hardware/mechanical-mounting/)
- [Revisions](https://opensourceneuro.github.io/Spikeling/hardware/revisions/)
- [Known hardware issues](https://opensourceneuro.github.io/Spikeling/hardware/known-hardware-issues/)
- [Safety and handling](https://opensourceneuro.github.io/Spikeling/hardware/safety-and-handling/)

### **Quickstart / use**
- [What you need](https://opensourceneuro.github.io/Spikeling/quickstart/what-you-need/)
- [Hardware setup](https://opensourceneuro.github.io/Spikeling/quickstart/hardware-setup/)
- [Flash firmware](https://opensourceneuro.github.io/Spikeling/quickstart/flash-firmware/)
- [First experiment](https://opensourceneuro.github.io/Spikeling/quickstart/first-experiment/)

### **Reference**
- [Device overview](https://opensourceneuro.github.io/Spikeling/user-guide/device-overview/)
- [Controls and I/O](https://opensourceneuro.github.io/Spikeling/user-guide/controls-and-io/)
- [Specs](https://opensourceneuro.github.io/Spikeling/reference/specs/)
- [Pinout and connectors](https://opensourceneuro.github.io/Spikeling/reference/pinout-and-connectors/)

### **Related repository folders**
- [Firmware](../Firmware)
- [Software](../Software)
- [Documentation](../Documentation)

---

## **11. Contributing hardware changes**

Contributions are welcome for:

- new board revisions
- BOM cleanup and sourcing notes
- manufacturing outputs
- assembly photos and bring-up procedures
- known-issue tracking and validated fixes
- connector diagrams and calibration procedures

When submitting hardware changes, it helps to include:
- board revision name
- schematic / PCB source files
- fabrication outputs if relevant
- BOM updates
- assembly notes
- photos or annotated screenshots
- compatibility notes with firmware and GUI versions

---

## **12. License**

Spikeling hardware is released under the **CERN Open Hardware Licence – Strongly Reciprocal v2.0 (CERN-OHL-S-2.0)**.

See:
- [`../LICENSES`](../LICENSES)
- [`../LICENSE.txt`](../LICENSE.txt)

Software and firmware are released separately under **GPL-3.0-or-later**.

If you reuse or modify the hardware, keep the appropriate license notices and attribution.

---

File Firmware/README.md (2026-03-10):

<p align="left">
  Spikeling logo
</p>

<div align="center">

# **Upload firmware and install drivers**

<p>
  <a href="../LICENSES/GPL-3.0-or-later.txt">
    
  </a>
  <a href="./Spikeling_V2.5">
    
  </a>
  <a href="./Spikeling_V3">
    
  </a>
  <a href="https://opensourceneuro.github.io/Spikeling/firmware/">
    
  </a>
</p>

</div>

Spikeling firmware is written in Arduino-style C++ and runs on ESP32-based hardware. This page explains how to install the Arduino IDE, add ESP32 board support, install the required libraries, select the correct board target, and upload firmware to either **Spikeling v2.x** or **Spikeling v3.x**.

**Quick links**
- [Spikeling v2.5 source](./Spikeling_V2.5)
- [Spikeling v3 source](./Spikeling_V3)
- [Bundled libraries](./Librairies)
- [Firmware documentation](https://opensourceneuro.github.io/Spikeling/firmware/)
- [Quickstart: Flash firmware](https://opensourceneuro.github.io/Spikeling/quickstart/flash-firmware/)

<p align="right">
  developed by M.J.Y. Zimmermann<br>
  maintained by P. Rignanese & A. Koumoundourou<br>
  based on an original idea by T. Baden
</p>

---

## **1. Choose your hardware version**

### **Spikeling v2.x**
- Based on an **ESP32 WROOM-32**
- Connected through a **USB-to-UART bridge**
- Usually requires the **CP210x driver**
- Firmware folder: [`./Spikeling_V2.5`](./Spikeling_V2.5)

### **Spikeling v3.x**
- Based on an **ESP32-S3 WROOM-1**
- Uses **native USB**
- Usually does **not** require a separate USB-to-UART driver
- Firmware folder: [`./Spikeling_V3`](./Spikeling_V3)

> The Arduino IDE setup is largely shared across both generations. The main differences are the board target, USB behaviour, and the additional DAC library required for v3.x.

---

## **2. Install Arduino IDE**

Download and install the Arduino IDE from the official website:

- [Arduino IDE download page](https://www.arduino.cc/en/software)

---

## **3. Install the ESP32 board package**

Once the Arduino IDE is installed, add the Espressif ESP32 board support package.

### **Step 1 — Open Preferences**

In Arduino IDE, go to:

**File > Preferences**

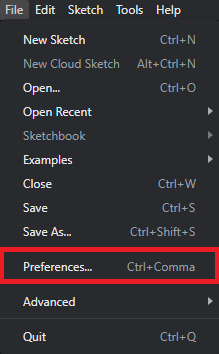
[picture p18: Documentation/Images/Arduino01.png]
Arduino IDE Preferences window


### **Step 2 — Add the ESP32 board manager URL**

Paste the following into **Additional Board Manager URLs**:

```text
https://raw.githubusercontent.com/espressif/arduino-esp32/gh-pages/package_esp32_index.json
```

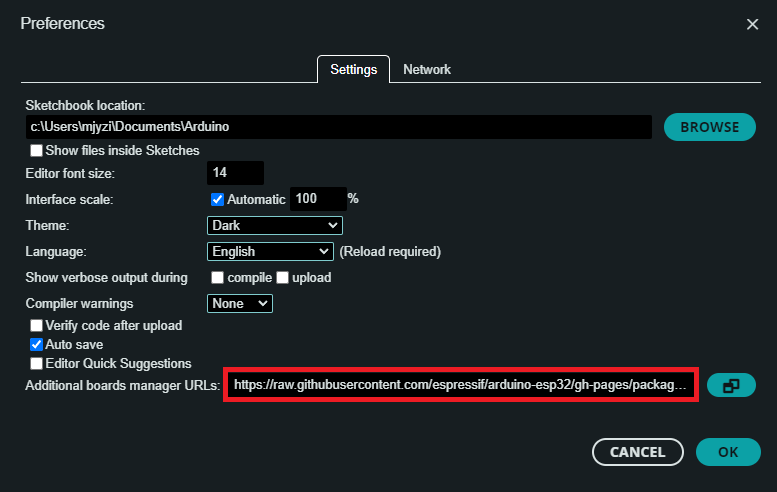
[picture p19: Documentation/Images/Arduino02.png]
Additional Board Manager URLs field


Then click **OK**.

### **Step 3 — Install the ESP32 package**

Open:

**Tools > Board > Boards Manager...**

Search for **ESP32** and install:

**ESP32 by Espressif Systems**

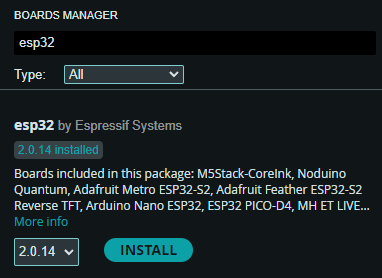
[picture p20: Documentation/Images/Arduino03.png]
Boards Manager install ESP32 by Espressif Systems


---

## **4. Install required libraries**

Open:

**Sketch > Include Library > Manage Libraries...**

Then search and install the libraries below.

### **Core libraries**
- **Arduino-SerialCommand** — Shyd (based on Steven Cogswell)  
  <https://github.com/shyd/Arduino-SerialCommand>
- **Gaussian** — Ivan Seidel  
  <https://github.com/ivanseidel/Gaussian>
- **MCP_ADC** — Rob Tillaart  
  <https://github.com/RobTillaart/MCP_ADC>

### **Additional library for Spikeling v3.x**
- **MCP_DAC** — Rob Tillaart  
  <https://github.com/RobTillaart/MCP_DAC>

### **Optional libraries for Wi-Fi / extended branches**
- **arduinoWebSockets** — Markus Sattler  
  <https://github.com/Links2004/arduinoWebSockets>
- **ArduinoJson** — Benoit Blanchon  
  <https://arduinojson.org/>

Libraries can also be installed manually from the repository folder:

- [Bundled libraries](./Librairies)

**Windows Arduino libraries folder**
```text
C:/Users/<your-user-name>/Documents/Arduino/libraries
```

---

## **5. Open the firmware sketch**

Open the `.ino` file that matches your hardware:

- **Spikeling v2.x** → `Spikeling_V2.5/Spikeling_V2.5.ino`
- **Spikeling v3.x** → `Spikeling_V3/Spikeling_V3.ino`

Keep the `.ino`, `.h`, and associated source files together in the same folder.

---

## **6. Select the correct board target (FQBN)**

### **For Spikeling v2.x**
Select:

**Tools > Board > esp32 > ESP32 Dev Module**

Select ESP32 Dev Module

### **For Spikeling v3.x**
Select:

**Tools > Board > esp32 > ESP32S3 Dev Module**

Select ESP32S3 Dev Module

For **Spikeling v3.x**, also confirm these Arduino IDE settings:

```text
Core / Board
  Tools > Board:                 ESP32S3 Dev Module
  Tools > USB Mode:              Hardware CDC and JTAG (wording may vary)
  Tools > USB CDC On Boot:       Enabled

CPU / Flash / PSRAM
  Tools > CPU Frequency:         240MHz
  Tools > Flash Frequency:       80MHz
  Tools > Flash Mode:            QIO 80MHz
  Tools > Flash Size:            4MB
  Tools > PSRAM:                 Disabled
```

---

## **7. Driver installation**

### **Spikeling v2.x**
Spikeling v2.x uses a CP210x USB-to-UART bridge. Install the Silicon Labs **CP210x** driver so the board appears as a serial / COM port.

- [CP210x driver page](https://www.silabs.com/developers/usb-to-uart-bridge-vcp-drivers)
- [CP210x downloads](https://www.silabs.com/developers/usb-to-uart-bridge-vcp-drivers?tab=downloads)

After installation, unplug and reconnect the board.

### **Spikeling v3.x**
Spikeling v3.x uses the ESP32-S3 native USB interface, so a separate USB-to-UART driver is generally not required.

---

## **8. Compile and upload**

1. Connect the board to your computer.
2. Select the correct serial port in:

   **Tools > Port**

3. Click **Verify** to compile the firmware.
4. Click **Upload** to flash the board.

Before uploading, close any software that may already be using the serial port, such as:
- the Spikeling GUI
- Arduino Serial Monitor
- PuTTY, CoolTerm, or other serial terminals

Only one application can use the serial port at a time.

---

## **9. If upload fails**

Common causes include:
- wrong board target selected
- wrong serial port selected
- missing Arduino library
- serial port already in use
- the ESP32 not entering bootloader mode

A common recovery sequence on many ESP32 boards is:

1. Hold **BOOT**
2. Tap **RESET** or **EN**
3. Release **BOOT** when the upload starts

If your board does not expose BOOT / RESET buttons, check the PCB silkscreen or the project documentation for the exact procedure.

---

## **10. Verify after flashing**

After a successful upload:

1. Unplug and reconnect the board
2. Launch the Spikeling GUI
3. Select the correct serial port
4. Confirm that the GUI connects and live traces are received

If the GUI connects but the behaviour is incorrect, first confirm that the uploaded firmware matches the hardware generation:

- `Spikeling_V2.5` for **v2.x hardware**
- `Spikeling_V3` for **v3.x hardware**

---

## **11. Troubleshooting checklist**

### **Board does not appear in Tools > Port**
- reinstall the CP210x driver for v2.x
- try another USB cable
- unplug and reconnect the board
- try another USB port

### **Compilation fails with a missing library error**
- install the missing library through **Manage Libraries**
- check whether it belongs in your Arduino `libraries` folder
- confirm the library folder name is correct

### **Upload starts but never completes**
- close the GUI and all serial monitors
- verify the board target again
- retry using bootloader mode

### **Firmware uploads but the GUI does not respond**
- confirm the correct firmware version was uploaded
- reconnect the board
- select the correct serial port in the GUI
- test with a fresh re-flash after a clean compile

---

## **Related links**

- [Main repository](https://github.com/OpenSourceNeuro/Spikeling)
- [Firmware folder](https://github.com/OpenSourceNeuro/Spikeling/tree/main/Firmware)
- [Firmware documentation](https://opensourceneuro.github.io/Spikeling/firmware/)
- [Quickstart: Flash firmware](https://opensourceneuro.github.io/Spikeling/quickstart/flash-firmware/)

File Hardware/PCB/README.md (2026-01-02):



SPDX-License-Identifier: CERN-OHL-S-2.0

This directory contains the hardware design sources (KiCad schematics/PCBs, fabrication outputs).
Copyright (c) 2026 OpenSourceNeuro contributors.

Source Location: https://github.com/OpenSourceNeuro/Spikeling
License text: see PCB/LICENSE (CERN-OHL-S v2)

<h1 align="center"> Spikeling v2 - Assembly Manual</h1></p>

<br></br>

## Overview

<p align="justify">
This page contains detailed assembly instructions for both version of La Spikeling unit, and includes a parts list for purchasing all electronics components.
Instructions on how to upload and update the microcontroller code and how to calibrate the device can be found <a href="https://github.com/OpenSourceNeuro/Spikeling-V2/tree/main/Instruction%20Manual"> <strong>on the instruction manual</strong> </a>.
Instructions regarding the GUI and on how to design stimuli can be found <a href="https://github.com/OpenSourceNeuro/LED-Zappelin-V2/blob/main/GUI_UserManual.md"><strong>here</strong></a>
</p>

***

- [Ordering PCB](#Ordering-the-PCB)
- [Assembling Spikeling](#Assembly)
- [Acrylic Covers](#Acrylic-Covers)

***

## Ordering the PCB

<p align="justify">
First step consist in getting the printed circuit board (PCB).
The PCB source files were designed on <a href="http://kicad.org/">KiCAD 9.0</a> and are available here to be modified by users if need be.
Users can find the "Gerber" files (zipped in the gerber folder) that companies (i.e. <a href="https://jlcpcb.com">JLCPCB</a>) will request to manufacture PCBs.
</p>

<p >


</p>

<br></br>

***
***

## Assembly

## Acrylic Covers

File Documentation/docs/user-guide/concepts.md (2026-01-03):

# **Concepts**

This page introduces the minimum set of concepts needed to use Spikeling effectively. It is written for quick scanning: each section links a familiar neuroscience idea (current clamp, spikes, synapses) to what you can **see, touch, and measure** on the device and in the GUI.

If you are new: read this once, then return to it while doing Quickstart and the first teaching labs.

---

## **The core idea: practise electrophysiology-style experiments without a full rig**

In a traditional patch-clamp setup, you inject a known current into a neuron and measure the resulting membrane potential (**Vm**), including whether and how the cell fires action potentials. Spikeling recreates this workflow with:

- a compact hardware device implementing a spiking neuron model
- a desktop GUI that provides real-time visualisation and stimulus generation
- a data export path (CSV) supports the same downstream analysis you would do for real electrophysiology

The goal is not to replace patch-clamp hardware, but to make the **logic of electrophysiology** accessible, interactive, repeatable, and teachable.
It is designed to let students practise *the reasoning* of electrophysiology: input–output relationships, excitability, adaptation, synaptic integration, and network interactions.  
(See also: [Device overview](device-overview.md), [GUI overview](gui-overview.md).)

---

## **Signals you will see (what the traces mean)**

### **Membrane potential (Vm), red**

**Vm** is the main signal. It represents the “state” of the neuron model. It is the trace students learn to read first.

Typical behaviours you will observe:

- **Resting baseline**: stable Vm without spiking
- **Hyperpolarisation**: Vm shifts downward (more negative)
- **Depolarisation**: Vm shifts upward (more positive)
- **Spikes**: rapid events when Vm crosses threshold and the model generates an action potential
- **Adaptation**: with sustained input, spikes may slow down over time

In Spikeling teaching labs, most conclusions come from how Vm changes in response to input.

!!! tip "Teaching tip"
    Early teaching wins come from having students predict: “If I increase depolarising current, what should Vm do? When should spikes appear? What should happen to firing rate over time?”

### **Input current (current clamp logic)**

Spikeling is used primarily in a **current-clamp style** workflow: you control an input current and observe Vm.

There are two common ways the input is applied:

- **Direct current injection (DC)** using the on-board **current injection potentiometer**
- **Programmed stimuli** (steps, pulses, trains, noise) initiated from the GUI

These correspond to the same conceptual action: changing the net input current over time.

### **Trigger / digital events**

Many workflows include a digital marker (often called **trigger**) that indicates when a stimulus begins/ends or when a protocol event occurs.

This is used to align traces during analysis and to segment recordings into “baseline vs stimulation” windows.

---
### **Total input current (Itot), green**

In addition to Vm, Spikeling can display a **current trace** that represents the **total input drive** entering the neuron model (**Itot**). This is useful because it makes explicit that the neuron is responding to a *sum* of inputs.

Itot typically includes contributions from:

- **Direct current injection** (current injection potentiometer)
- **Photodiode input** (light converted into current; Photo-gain sets sign and gain)
- **Noise input** (Gaussian noise, adjustable amplitude)
- **Synaptic inputs** (spike-triggered exponentially decaying currents from Synapse 1 and 2)

!!! tip "Teaching tip"
    Encourage students to interpret experiments as: **Itot (input) → Vm (state) → spikes (output)**.  
    When something “unexpected” happens, Itot is often the quickest way to see which input pathway is dominating.

---

## **The most important control: current injection potentiometer**

Spikeling includes a **centre-detent potentiometer** representing direct current injection from a patch pipette.

- **Centre detent**: 0 current (no injection)
- Turn **left**: hyperpolarising current (Vm decreases)
- Turn **right**: depolarising current (Vm increases)

This control is deliberately physical and immediate: it is the fastest way to demonstrate the transition:

**silent → depolarised → spiking → spike-frequency adaptation**

(Quickstart uses this to teach “how to drive Vm” before introducing more structured protocols.)

---

## **Threshold and excitability (why spiking starts)**

Spiking starts when Vm crosses an effective **threshold**. The threshold is not a fixed “line” in all neuron models—many models have state-dependent dynamics—but for teaching, a useful mental model is:

- below threshold: inputs shift Vm but do not spike
- near threshold: small changes can trigger spikes
- above threshold: repeated spiking occurs

This is what makes neurons **excitable**: a small difference in input can qualitatively change the output.

---

## **Adaptation (why firing slows down)**

Many neurons show **spike-frequency adaptation**: a constant depolarising input initially produces fast spiking, then the spiking rate slows.

In Spikeling, you can see adaptation by:

1. Turning the current injection potentiometer rightward enough to cause sustained spiking
2. Holding it steady for several seconds
3. Watching the interval between spikes increase over time

In experiments, adaptation is often summarised by an **F–I curve** (firing rate vs input current) and by comparing early vs late firing rate during a step.

---

## **The neuron model: Izhikevich dynamics and “modes”**

Spikeling uses an **Izhikevich-style** spiking neuron model, which is widely used in computational neuroscience because it can reproduce diverse firing patterns with a compact set of equations and a small number of parameters.

### **What changes when you change “mode”**
A “mode” changes the four key parameters of the Izhikevich formulation (commonly labelled **a, b, c, d**), which tune:

- recovery/adaptation dynamics
- spike reset behaviour
- whether the neuron behaves more like regular-spiking, fast-spiking, bursting, etc.

### **How modes are selected (board revision detail)**

- **Board v2.x**: an on-board **Mode** button cycles through **12 preset modes**
- **Board v3.x**: neuron mode is selected from the **GUI** (no on-board cycling)

!!! note
    Mode selection changes the model’s intrinsic excitability and adaptation. For teaching, it is useful to keep the stimulus fixed and show how different modes produce different firing patterns.

---
## **Stimulus protocols: what is built in vs what the GUI adds**

A stimulus protocol is simply the time-course of injected input.

### **On-board stimulus (default)**
By default, the board provides a **square-wave stimulus** where users can adjust:

- **frequency** (how fast it repeats)
- **strength** (amplitude)

This is ideal for rapid classroom demonstrations: “change frequency, change strength, watch Vm.”

### **GUI stimulus modes (built-in)**
The GUI expands stimulus generation for proper protocol settings. Out of the box, users can select:

- **Steps** (baseline → constant input → baseline)
- **Sine waves**
- **Triangle waves**
- **Chirps / ZAP-style sweeps**
  (linear sweep, exponential sweep, and amplitude-increasing variants)
- **Noise**

These waveforms are standard in electrophysiology and modelling for probing excitability, resonance/impedance, temporal integration, and variability.

### **Custom stimuli**
Beyond built-in modes, the GUI supports imported user-defined/custom stimuli. This is the bridge from “following a lab handout” to “designing your own protocol”.

!!! tip "Teaching tip"
    Treat the stimulus generator as a “function generator for neurons”. Have students state the hypothesis first (“I think this neuron prefers low frequencies”), then choose a waveform that tests it (e.g., a chirp).

---

## **Noise input: why spikes can become stochastic**

Real neurons are never perfectly quiet: thermal (Johnson–Nyquist) noise, ion channel fluctuations, synaptic background activity, and measurement noise all add variability. This is one reason spike timing can be **probabilistic**, especially near threshold.

Spikeling includes an on-board **Noise** potentiometer that generates **Gaussian noise** added to the input drive.

- Increasing the Noise potentiometer increases the **noise amplitude**
- Noise is summed into the **total input current (Itot)**
- Near threshold, noise can:
  - trigger occasional spikes (“stochastic spiking”)
  - jitter spike timing (reduced precision / increased variability)
  - reveal that small differences in Vm can change spike outcome

!!! tip "Teaching tip"
    A simple classroom demonstration is to set the neuron *just below* spiking with the current injection potentiometer, then slowly increase Noise. Students will see spiking emerge intermittently without changing the mean input—illustrating variability-driven threshold crossings.
---

## **Light input: photodiode as a visual sensory stimulation pathway**

Spikeling includes a **photodiode** that converts changes in light intensity into an input current pathway for the neuron model. Conceptually, this is intended to mimic a **visual sensory experiment**: light is used as the stimulus (as in retinal stimulation), and the neuron’s response is read out as **Vm and spikes**.

### **Two ways to deliver light stimuli**

1. **Controlled light stimulation (recommended): LED stimulus cable**  
   Use the dedicated **LED cable** plugged into the **stimulus output port**. This allows the GUI (or on-board stimulus) to drive the LED with precise timing and amplitude, producing reproducible light flashes or flicker patterns aimed at the photodiode.

2. **Flexible demonstrations: external light source**  
   You can also use **any external LED/light source** aimed at the photodiode (for example, a handheld LED, a lamp with modulation, or another experimental light source) to deliver a stimulus. This is useful for quick classroom demonstrations and exploratory setups.

### **Photodiode gain and polarity (Photo-gain potentiometer)**

The **Photo-gain** potentiometer controls how strongly light is converted into input drive, and can be set with either polarity:

- **Positive gain**: increased light produces a **depolarising** effect (Vm tends to rise)
- **Negative gain**: increased light produces an **inhibitory/hyperpolarising** effect (Vm tends to fall)

This lets you demonstrate both “excitatory” and “inhibitory” sensory drive using the same light stimulus, and it supports classic teaching questions such as: *How does stimulus intensity affect firing rate? What changes when the sign of sensory input is inverted?*

---

## **Synapses and networks: two synaptic inputs**

Spikeling can receive up to **two synaptic inputs** from other Spikeling units.

### **Physical concept**
A cable from the **axon output** of a second unit into one of the **synaptic input** jacks transmits:

- a spike event (digital) and
- Vm (analogue)

### **What the synapse does**
When a presynaptic spike arrives, the receiving unit generates an **exponentially decaying synaptic current** (a classic simplified postsynaptic current model).

Each synapse has its own gain potentiometer:

- **Synapse 1 gain**: positive (excitatory) or negative (inhibitory)
- **Synapse 2 gain**: positive (excitatory) or negative (inhibitory)

This lets students practise the most important network idea in neuroscience:

> spikes from one neuron can drive or suppress another neuron, depending on sign and strength of synaptic coupling.

(See also: [Synapses and inputs](../experiments/synapses-and-inputs.md), [Network with two units](../experiments/network-two-units.md).)

---
## **Multisensory feedback: LED and buzzer**

Spikeling provides immediate “non-screen” feedback:

- **On-board LED** follows Vm and blinks strongly on spikes
- **On-board buzzer** clicks at each spike

These are not just cosmetic: they help students build intuition about spiking without staring at plots, which is useful in classroom demonstrations and outreach settings.
They can also be deactivated if they become annoying to the user or the class

---
## **Channels, connectors, and grounding (practical concept)**

Spikeling uses stereo **3.5 mm TRS** connectors:

- **Tip (T)**: digital (commonly trigger)
- **Ring (R)**: analogue (commonly Vm or stimulus signal, depending on the jack)
- **Sleeve (S)**: ground

Good grounding and short cables matter. Many “mystery noise” issues reduce to an incomplete ground reference or a swapped cable.

(See: [Controls and I/O](controls-and-io.md) and [Quickstart → Troubleshooting](../quickstart/troubleshooting.md).)

---

## **Emulator vs hardware (why both exist)**

Spikeling includes an emulator mode to support:

- demonstrations without physical devices
- remote teaching and workshops
- rapid development and testing of GUI workflows

Conceptually, the emulator behave like the hardware from the user’s point of view: you apply inputs, observe Vm/spiking, record, and analyse.

---

## **Fluorescence imaging simulation (why Vm can become fluorescence)**

Spikeling can simulate fluorescence imaging by transforming Vm into:

1. a simulated intracellular calcium trace
2. a simulated fluorescence readout

This helps connect spike-driven Vm dynamics to calcium transients and fluorescence signals commonly used in modern systems neuroscience.

(See: [Fluorescence imaging simulation](fluorescence-imaging-sim.md).)

--

## **What to read next**

- Physical layout and signals: [Device overview](device-overview.md)
- Knobs, jacks, and I/O: [Controls and I/O](controls-and-io.md)
- GUI workflow: [GUI overview](gui-overview.md)
- Export + analysis: [Recording and export](recording-and-export.md)

---

## **References (background reading)**

1. Izhikevich EM (2003). *Simple model of spiking neurons.* IEEE Trans Neural Networks. https://www.izhikevich.org/publications/spikes.pdf
2. Moleculardevices (overview). *What is current-clamp?* https://www.moleculardevices.com/applications/patch-clamp-electrophysiology/what-current-clamp-method
3. Hutcheon B, Yarom Y (2000). *Resonance, oscillation and the intrinsic frequency preferences of neurons.* Trends Neurosci. https://pubmed.ncbi.nlm.nih.gov/10782127/
4. Gerstner W, Kistler W, Naud R, Paninski L (online book). *Neuronal Dynamics: Synapses (exponential/biophysical synapse models).* https://neuronaldynamics.epfl.ch/online/Ch3.S1.html
5. Vogelstein JT et al. (2009). *Spike inference from calcium imaging using sequential Monte Carlo methods.* Biophys J. https://pubmed.ncbi.nlm.nih.gov/19619479/

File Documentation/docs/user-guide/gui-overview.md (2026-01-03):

# **GUI overview**

This page explains how to use the Spikeling desktop GUI as a teaching and experiment interface. It is written for quick scanning: each section maps a visible GUI element (button, slider, panel) to a neuroscience task (stimulate, record, analyse).

If you are new, start with **Neuron Interface** and learn the workflow: **connect → stimulate → observe → record → analyse**.

See also: [Device overview](device-overview.md), [Controls and I/O](controls-and-io.md), and [Concepts](concepts.md).

---

## **Mental model: what the GUI is doing**

Think of the GUI as three things at once:

1. **An oscilloscope** (plots Vm and other traces in real time)
2. **A stimulus generator** (built-in waveforms + custom/imported protocols)
3. **A lab notebook** (recording to CSV and quick analysis)

Spikeling itself is the “preparation”: it integrates inputs (current injection, stimulus, light, synapses, noise) and produces outputs (Vm, spikes, axon output). The GUI makes those signals visible and controllable.

---

## **Left-hand navigation: workspaces**

The GUI is organised into workspaces accessed from the left menu:

- **Spikeling**
  - **Neuron Interface** (hardware-connected oscilloscope + controls)
  - **Neuron Emulator** (same interface, but simulated)
  - **Data Analysis** (load CSV, detect spikes, averages, export)
  - **Tutorial** (guided teaching pages)
- **Imaging**
  - **Imaging Simulation** (Vm → calcium → fluorescence; optional ΔF/F)
  - **Data Analysis**
  - **Tutorial** (guided teaching pages)
- **Neuron Generator** (build/edit neuron modes and parameters)
- **Stimulus Generator** (build/save waveforms for later use)
- **Exercises** (teaching labs and instructions)
- **Settings** (preferences and configuration)
- **About**
- **Help**
- **GitHub**

### **Hide/Show menus**
Buttons such as **Hide Menus** / **Hide Sub-Menus** are purely for screen space: they do not change any model settings. Use them when teaching on a projector or a small screen.

---

## **Spikeling → Neuron Interface (hardware mode)**

This is the primary teaching screen. You will typically use it for:
- basic excitability demonstrations (current clamp style)
- stimulus-response experiments (frequency/strength sweeps, chirps, noise)
- synaptic integration (two-unit or three-unit networks)
- structured recording for later analysis

### **1) Connect to a device**

1. Plug the Spikeling board in via USB.
2. In the top bar, choose the correct **COM/serial port**.
3. Click the **Connect** button.

**Tip:** if several ports are listed, the correct one often produces visible LED activity on the device when selected.

If connection fails, see the troubleshooting box below.

!!! tip "Teaching tip"
    Start with the device in a stable baseline (no spiking), then move deliberately: show how small changes near threshold can switch the output from silent to spiking.

### **2) What you see on the oscilloscope (central plot)**

The oscilloscope can display multiple traces simultaneously. The most important are:

- **Vm** (membrane potential): the “main readout”, red
- **Input current / total drive**: the net current the model receives, green
- **Stimulus**: the waveform being applied (board square-wave or GUI waveform), blue

When synaptic inputs are used, additional traces can be enabled for:
- **Synapse 1** (presynaptic Vm and/or synaptic current) orange/cyan
- **Synapse 2** (presynaptic Vm and/or synaptic current) yellow/magenta

Use the trace tick-boxes to declutter the view when teaching.

!!! note
    The **input current/total drive trace** is especially useful for teaching because it reflects the *sum* of pathways: direct current injection, stimulus, photodiode/light drive, synaptic currents, and added noise.

### **3) Speed control (display rate)**
A **Speed** slider and multiplier controls how quickly the oscilloscope advances in time (and/or how densely points are displayed). Use it to:
- slow down fast spiking for explanation
- speed up for long recordings or adaptation demonstrations

### **4) Neuron mode selection**
Neuron “modes” are named patterns (parameter sets) for the Izhikevich-style model (e.g., tonic spiking, phasic spiking, bursting, adaptation, etc.).

Typical workflow:
1. Select a mode from the **Neuron Mode** drop-down list.
2. Click **Apply** to push the change.

You can also **Browse** to load a custom neuron definition created in **Neuron Generator**.

!!! tip "Teaching tip"
    Keep the stimulus fixed and change only the mode. This isolates the concept that *intrinsic membrane dynamics* (not just input strength) shapes firing patterns.

### **5) LED and buzzer controls (classroom ergonomics)**
Top-right controls toggle:
- the **Vm LED** behaviour (visual feedback)
- the **buzzer** click on spikes (auditory feedback)

In a quiet teaching room, it is often worth muting the buzzer after the first demonstration.

### **6) The right-hand parameter panel (where most teaching happens)**

The right panel contains grouped controls. When a toggle button is activated, it automatically deactivates the knob on the board responsible for the selected variable. The exact grouping varies slightly across versions, but conceptually it contains:

#### **A) Stimulus controls**
- Adjust **Stimulus Frequency** and **Stimulus Strength** (board-like square wave control)
- Enable **Custom Stimulus** and **Load** a saved waveform (from Stimulus Generator)

Use the small stimulus preview plot to confirm what will be delivered before enabling it.

#### **B) Photo-receptor (photodiode) dynamics**
- **Photo-gain** (including sign: positive or negative gain)
- **Photo decay** and **Photo recovery** (shape of the light-evoked current)

Teaching use:
- demonstrate “transient vs sustained” sensory drive
- show how the same light input can excite or inhibit depending on gain polarity

#### **C) Patch Clamp**
When enabled, Patch clamp adds a DC offset to the neuron’s input drive. This is the most direct software analogue of patch pipette current injection:

- negative injected current tends to hyperpolarise Vm (less spiking)
- positive injected current tends to depolarise Vm (more spiking)
- zero is the neutral “no injection” point

This injected current is best thought of as baseline drive that can be combined with other inputs (stimulus waveforms, light input, synapses, noise).

!!! tip "Teaching use"
  Patch clamp is useful when you want a repeatable DC level (e.g., set the neuron just below threshold), then demonstrate how adding noise, synaptic input, or a stimulus waveform changes spiking.

#### **D) Noise**
Noise adds controlled variability to the total input drive.

Teaching use:
- stochastic spiking near threshold
- spike-time jitter
- realism: demonstrating that “no recording is noise-free”

A simple, effective classroom demo:
1. Set current injection just below spiking.
2. Increase noise until spikes occur intermittently.
3. Ask students why spike timing becomes unreliable near threshold.

#### **E) Synapse 1 / Synapse 2**
Each synapse has:
- a **gain** (positive = excitatory; negative = inhibitory)
- often a **decay** control (synaptic time constant shaping)

Teaching use:
- excitation vs inhibition
- temporal summation
- coincidence detection and competition (two inputs with different signs)

### **7) Recording (CSV logging)**
At the bottom of the screen:
1. Choose a **directory** (browse)
2. Enter a **filename**
3. Press **Record** to start logging

Recordings are saved as **CSV** for analysis in the GUI and in external tools (Python, MATLAB, R, etc.).

!!! warning
    If you reuse a filename, you may overwrite earlier recordings depending on your configuration. Consider a consistent naming convention (e.g., `mode_phasic_step_20s_01.csv`).

---

## **Spikeling → Neuron Emulator (no hardware required)**

The emulator reproduces the same user experience as the hardware screen:
- same plots
- same stimulus logic
- same neuron modes
- same recording pathway

Use it for:
- remote teaching and workshops
- classroom preparation without a physical unit
- debugging a protocol before running it on hardware

Typical workflow:
1. Open **Neuron Emulator**
2. Start the emulator
3. Use the same stimulus and parameter controls as in Neuron Interface
4. Record data exactly as you would with hardware

---

## **Spikeling → Data Analysis (quick classroom analysis)**

The analysis panel is designed for immediate feedback after a lab recording:

Typical workflow:
1. **Load Data**
2. Set a **Spike Threshold**
3. Display:
   - spike events (raster-like view)
   - spike rate over time
   - stimulus-aligned averages (when applicable)
4. **Export** results (CSV and/or images)

Teaching focus:
- show how threshold choice changes spike detection
- link stimulus structure to firing rate changes
- compare conditions (e.g., gain = 0 vs gain > 0 vs gain < 0)

---
## **Imaging → Imaging Simulation**

This workspace connects electrophysiology-style signals to modern imaging readouts.

Conceptually:
**Vm/spikes → simulated calcium transient → simulated fluorescence**

Common teaching use:
- explain why fluorescence is a filtered, delayed proxy for spiking
- compare “ground truth” Vm to fluorescence
- demonstrate ΔF/F and baseline normalisation

Typical controls include:
- selecting the **data source** (hardware vs emulator)
- choosing which traces to show (fluorescence, calcium, Vm)
- toggling **ΔF/F**
- recording fluorescence traces similarly to electrophysiology traces

---

## **Neuron Generator (build and save neuron modes)**

This workspace is for creating or editing neuron modes by adjusting model parameters (including the classic a, b, c, d parameter set). It is most useful for advanced teaching:

- exploring how parameter changes reshape firing patterns
- creating “custom neurons” for a lab class
- saving neuron definitions for reuse in Neuron Interface/Emulator

Recommended teaching approach:
- start from a known mode (e.g., tonic spiking)
- change *one parameter at a time*
- keep the stimulus fixed
- record before/after traces for comparison

---

## **Stimulus Generator (design waveforms for experiments)**

This workspace creates stimulation protocols beyond the board’s default square wave.

Common modes include:
- steps
- sine and triangle waves
- chirps / ZAP sweeps (linear, exponential, amplitude ramps)
- noise

Typical workflow:
1. Choose a stimulus type
2. Set parameters (amplitude, frequency, duration, ramps, inter-stimulus timing)
3. **Display Stimulus** to preview
4. **Save Stimulus**
5. Return to Neuron Interface/Emulator and **Load** it under Custom Stimulus

---

## **Troubleshooting: connection and “nothing is moving”**

If you do not see traces updating or cannot connect:

- Confirm the correct USB cable (some USB cables are power-only)
- Try a different USB port
- Select a different COM/serial port and retry
- Press **Reset** on the board (or unplug/replug)
- Close and reopen the GUI if the serial connection appears stuck

If the device connects but traces look flat:
- confirm at least one input pathway is active (current injection, stimulus, light, synapse)
- ensure the oscilloscope trace tick-boxes include **Vm**
- check that the speed/display rate is not effectively “paused” by settings

---

## **What to read next**

- Hardware signals and connectors: [Controls and I/O](controls-and-io.md)
- What the traces mean: [Concepts](concepts.md)
- Running your first protocol: [Quickstart](../quickstart/index.md)
- Recording and export conventions: [Recording and export](recording-and-export.md)

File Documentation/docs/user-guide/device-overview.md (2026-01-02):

# **Device overview**

This page gives a high-level tour of the Spikeling hardware: what is on the board, what each control influences, and how signals flow from inputs (current, light, synapses, stimuli) to outputs (Vm, spikes, axon output) and into the GUI.

For exact connector pinout and cable conventions, see: [Controls and I/O](controls-and-io.md).

---

## **At a glance: what the device does**

Spikeling implements a spiking neuron model in hardware and exposes it like a teaching-friendly electrophysiology preparation:

- multiple **input pathways** that contribute to the neuron’s net input drive
- a measurable **membrane potential (Vm)** output
- discrete **spike events** (for triggering, synchronisation, and network coupling)
- real-time streaming to a desktop GUI for visualisation, stimulation, and recording

---

## **Hardware revisions (v2.x vs v3.x)**

Spikeling exists in two main official board families:

### **v2.x (e.g., v2.5)**
- ESP32 WROOM-32
- mini-USB
- uses a CP210x USB-to-UART bridge (driver typically required)
- on-board **Mode** button cycles through **12 preset neuron modes**

### **v3.x (e.g., v3.0.1)**
- ESP32-S3 WROOM-1
- USB-C
- uses ESP32-S3 native USB (typically no extra driver required)
- includes an additional DAC IC compared to v2.x
- neuron mode is selected from the **GUI**
- additional power/control hardware for the **LiPo battery extension** (power switch)
- additional control to **disable the Vm LED** (useful in teaching environments)

!!! note
    The user workflow remains the same across revisions (stimulate → observe Vm/spikes → record/export). Differences mainly affect connection/driver behaviour, how neuron modes are selected, and a small number of extra convenience controls on v3.x.

---

## **Signal flow (mental model)**

A useful way to understand Spikeling is as a “summing junction” feeding a neuron model:

### **Input pathways (sources of drive)**
- **Current injection potentiometer** (centre-detent; left hyperpolarises, right depolarises)
- **On-board stimulus generator** (square-wave; adjustable frequency and strength)
- **GUI stimulus generator** (steps, sine, triangle, chirps, noise, and custom/imported waveforms)
- **Photodiode** (light → input drive; polarity and gain set by Photo-gain potentiometer)
- **Synapse 1 / Synapse 2 inputs** (from other Spikeling units; spike-evoked exponential synaptic currents; gain and sign adjustable)

### **Model and outputs**
- the neuron model generates **Vm**
- when Vm crosses threshold, a **spike event** is produced
- Vm and spikes are:
  - streamed to the GUI for display/recording
  - exposed through the board’s output connectors for networking and external use

---

## **On-board controls (what each one affects)**

The exact naming may vary slightly by revision/label, but the concepts are consistent:

| Control | What it does | Teaching use |
|---|---|---|
| Current injection (centre-detent) | Adds DC drive; left = hyperpolarising, right = depolarising | Threshold, excitability, adaptation |
| Stimulus strength | Sets square-wave amplitude | Input–output gain, recruitment into spiking |
| Stimulus frequency | Sets square-wave repetition rate | Frequency following, spike reliability |
| Noise (Gaussian) | Adds Gaussian noise to the input drive; amplitude set by Noise potentiometer | Variability, near-threshold stochastic spiking, spike-time jitter |
| Photo-gain (±) | Sets gain and polarity for photodiode input | Visual sensory stimulation analogue; excitation vs inhibition |
| Synapse 1 gain (±) | Sets strength/sign of synapse 1 (excitatory/inhibitory) | Synaptic integration; E/I balance |
| Synapse 2 gain (±) | Sets strength/sign of synapse 2 (excitatory/inhibitory) | Network motifs; coincidence and competition |
| Mode button (v2.x) | Cycles through 12 preset neuron modes (Izhikevich parameter sets) | Compare firing patterns under identical stimuli |
| Reset | Restarts the microcontroller/firmware (returns to a known state) | Quick recovery if the device stops responding |
| Buzzer mute | Disables the spike click/buzzer | Classroom comfort; reduce distraction |
| Vm LED disable (v3.x) | Disables the Vm-following LED/spike flash | Classroom comfort; reduce distraction |
| LiPo power switch (v3.x) | Enables/disables the LiPo battery extension power path | Safe power management for battery use |

!!! tip "Practical note"
    If the GUI does not detect the device, or the serial stream appears stuck, using **Reset** is the quickest way to return to a known state before troubleshooting cables, ports, or firmware.

### **Noise (Gaussian): why spikes can become stochastic**

The **Noise** potentiometer adds **Gaussian noise** to the neuron’s input drive. This makes the system feel more realistic and helps demonstrate a core idea in neuroscience: **near threshold, spike timing can be probabilistic**.

In practice, noise contributes to the **total input current (Itot)** alongside direct current injection, light input, synaptic inputs, and any programmed stimulus. With the neuron held just below threshold, increasing noise can:

- trigger occasional spikes without changing the mean input (“stochastic spiking”)
- introduce spike-time jitter (reduced timing precision)
- reveal that small fluctuations can determine whether a spike occurs

!!! tip "Teaching tip"
    Set the current injection potentiometer so Vm sits just below spiking, then slowly increase Noise. Students will see intermittent spiking emerge purely from fluctuations—an intuitive demonstration of variability-driven threshold crossings.

---

## **Neuron “modes” (Izhikevich parameter sets)**

Spikeling uses an Izhikevich-style neuron model. Different “modes” correspond to different parameter sets (a, b, c, d), changing intrinsic excitability and firing pattern.

- **v2.x**: an on-board **Mode** button cycles through 12 preset modes
- **v3.x**: neuron mode is selected from the **GUI** (20 preset modes)

---

## **Visual and auditory feedback (useful in teaching)**

Spikeling includes immediate non-screen feedback:

- **On-board LED** follows Vm and flashes strongly on spikes
- **On-board buzzer** clicks on each spike

These cues help students build intuition about spiking without needing to focus on plots continuously. They can be disabled if they become distracting.

---

## **Connectors (overview)**

Spikeling uses stereo **3.5 mm stereo jack** connectors to carry analogue and digital signals plus ground:

- **Tip (T)**: digital (commonly spike/trigger)
- **Ring (R)**: analogue (commonly Vm or stimulus, depending on jack)
- **Sleeve (S)**: ground

Common use patterns include:
- **Axon output** from one unit → **Synapse input** on another unit
- **Stimulus output** → LED cable → photodiode (controlled light stimulation)
- **Stimulus output** → **DC/current injection input** (use the waveform generator as injected current)

For the full mapping and recommended cables, see: [Controls and I/O](controls-and-io.md).

---

## **What to read next**

- Exact jack mapping and cable conventions: [Controls and I/O](controls-and-io.md)
- GUI signal layout and controls: [GUI overview](gui-overview.md)
- Recording/export workflow: [Recording and export](recording-and-export.md)

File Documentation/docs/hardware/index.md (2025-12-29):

# Hardware

Hardware build, assembly, calibration, and maintenance.

## Hardware overview

TODO

## Build vs buy

TODO

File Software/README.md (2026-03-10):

<p align="left">
  Spikeling logo
</p>

<div align="center">

# **Software applications, GUI, and development setup**

<p>
  <a href="../LICENSE.txt">
    
  </a>
  <a href="https://github.com/OpenSourceNeuro/Spikeling/releases">
    
  </a>
  <a href="../Software/GUI%20-%20PyQt6-PySide6">
    
  </a>
  <a href="../Software/App%20-%20AndroidStudioProjects">
    
  </a>
</p>

</div>

This folder contains the **software side of Spikeling**. At present, it is split into two main application tracks:

- a **cross-platform desktop GUI** built with **PyQt6 / PySide6**
- an **Android Studio mobile application project**

The desktop GUI is the main user-facing application used to communicate with Spikeling hardware, visualise data streams, configure experiments, and export recordings. The Android project is provided separately for mobile-oriented development.

**Quick links**
- [Main repository](../)
- [Firmware folder](../Firmware)
- [Hardware folder](../Hardware)
- [Documentation folder](../Documentation)
- [Desktop GUI source](./GUI%20-%20PyQt6-PySide6)
- [Android Studio project](./App%20-%20AndroidStudioProjects)
- [Project documentation](https://opensourceneuro.github.io/Spikeling/)
- [Releases](https://github.com/OpenSourceNeuro/Spikeling/releases)

<p align="right">
  developed by M.J.Y. Zimmermann<br>
  maintained by P. Rignanese & A. Koumoundourou<br>
  based on an original idea by T. Baden
</p>

---

## **1. What this folder contains**

The `Software` folder groups the applications used to interact with Spikeling hardware and its teaching workflows.

### **Current subfolders**
- [`GUI - PyQt6-PySide6`](./GUI%20-%20PyQt6-PySide6)  
  Main desktop application for Windows, macOS, and Linux
- [`App - AndroidStudioProjects`](./App%20-%20AndroidStudioProjects)  
  Android Studio project for mobile development

---

## **2. Software overview**

### **Desktop GUI**
The desktop GUI is the central application for most Spikeling users. It is designed for:

- real-time signal visualisation
- experiment control
- serial communication with the device
- stimulus generation
- data recording and export
- teaching workflows spanning electrophysiology, imaging, and analysis

### **Android app**
The Android project is a separate software track intended for mobile development and Android-based use cases. It is stored as a standard Android Studio / Gradle project.

> For most users, the desktop GUI is the primary entry point. The Android project is best treated as a developer-oriented companion project unless your workflow specifically targets Android devices.

---

## **3. Desktop GUI structure**

The desktop application currently lives in:

- [`./GUI - PyQt6-PySide6`](./GUI%20-%20PyQt6-PySide6)

Its structure shows a modular design with separate pages and graph logic for different parts of the Spikeling ecosystem.

### **Main entry points and core files**
- `Main.py`
- `serial_manager.py`
- `Spikeling_UI.py`
- `Spikeling_UI.ui`
- `resources.qrc`
- `resources_rc.py`

### **Graph / acquisition modules**
- `Graph_Spikeling.py`
- `Graph_Imaging.py`
- `Graph_ExtraCellular.py`
- `Graph_Emulator.py`

### **GUI page modules**
- `Page_Home.py`
- `Page_About.py`
- `Page_Settings.py`
- `Page_GitHub.py`

### **Neuron / experiment pages**
- `Page_Spikeling_NeuronInterface.py`
- `Page_Spikeling_NeuronEmulator.py`
- `Page_Spikeling_DataAnalysis.py`
- `Page_StimulusGenerator.py`
- `Page_NeuronGenerator.py`
- `Page_NeuronParameters.py`

### **Imaging pages**
- `Page_Imaging_ImagingSimulation.py`
- `Page_Imaging_DataAnalysis.py`
- `Page_Imaging_Tutorial.py`

### **Extracellular pages**
- `Page_ExtraCellular_Scope.py`

### **Supporting parameter modules**
- `Parameters_Izhikevich.py`
- `Parameters_GECI.py`
- `Parameters_Settings.py`
- `Parameters_Sliders.py`
- `Parameters_ToggleButtons.py`
- `Parameters_NavigationButtons.py`

### **Bundled resources / user content folders**
- `Neurons`
- `Stimuli`
- `Recordings`
- `resources`

This structure makes it clear that the GUI is not just a serial monitor: it is a full teaching and experiment environment covering live neuron interaction, stimulus design, imaging simulation, extracellular/tetrode simulation, and data analysis.

---

## **4. Android project structure**

The Android application currently lives in:

- [`./App - AndroidStudioProjects`](./App%20-%20AndroidStudioProjects)

This folder contains a standard Android Studio / Gradle project layout, including:

- `app/`
- `gradle/`
- `build.gradle.kts`
- `settings.gradle.kts`
- `gradle.properties`
- `gradlew`
- `gradlew.bat`

This means Android development is organised as a separate native application project rather than being embedded inside the Python GUI codebase.

---

## **5. Desktop GUI dependencies**

The current pinned Python dependencies listed in `GUI - PyQt6-PySide6/requirements.txt` are:

```text
PySide6==6.9.2
numpy==2.3.2
pandas==2.3.2
pyinstaller==6.15
pyqtgraph==0.13.7
scipy==1.16.1
```

These dependencies reflect the current desktop software stack:

- **PySide6** for the Qt-based GUI
- **pyqtgraph** for fast scientific plotting
- **numpy / scipy** for numerical processing
- **pandas** for tabular data handling and export workflows
- **pyinstaller** for packaging distributable desktop applications

---

## **6. Platform packaging**

The desktop GUI folder includes dedicated PyInstaller spec files for the main desktop operating systems:

- `Spikeling-win.spec`
- `Spikeling-mac.spec`
- `Spikeling-linux.spec`

This means the repository is already organised for cross-platform packaged builds, not only source-based execution.

If you are building from source, these spec files are useful references for:
- included resources
- packaging behaviour
- OS-specific build workflows

---

## **7. Releases and pre-built software**

Pre-built software packages are distributed through the project’s GitHub releases page:

- [Spikeling releases](https://github.com/OpenSourceNeuro/Spikeling/releases)

This is the recommended entry point for users who want to install the GUI without setting up a local Python environment.

If you are a contributor or developer, the source folders in this directory provide the editable codebase used to create those packaged releases.

---

## **8. What the desktop software is used for**

The desktop GUI extends Spikeling beyond simple live monitoring. Based on the current repository structure and project documentation, the software supports workflows such as:

- live membrane voltage and spike visualisation
- serial communication with Spikeling hardware
- data recording and export
- built-in data analysis pages
- neuron parameter editing
- custom stimulus generation
- neuron emulation
- fluorescence imaging simulation
- extracellular / tetrode-style simulation
- tutorial and teaching pages

This architecture is particularly important for teaching, because it lets students move from **stimulation** to **recording** to **analysis** in one interface.

---

## **9. Recommended usage paths**

### **For end users**
Use a pre-built release when available:
1. download the latest GUI release
2. install / unpack it on your platform
3. connect your Spikeling device
4. launch the GUI and select the correct serial port

### **For developers**
Work from the `GUI - PyQt6-PySide6` source folder:
1. create a Python virtual environment
2. install the dependencies from `requirements.txt`
3. run the GUI locally
4. use the PyInstaller spec files when preparing distributable builds

### **For Android developers**
Open `App - AndroidStudioProjects` directly in Android Studio and work through the Gradle-based project.

---

## **10. Example desktop development setup**

A typical local setup for the desktop GUI is:

```bash
cd "Software/GUI - PyQt6-PySide6"
python -m venv .venv
source .venv/bin/activate
pip install -r requirements.txt
python Main.py
```

On Windows, activation is typically:

```bash
.venv\Scripts\activate
```

> Exact launch steps may vary depending on your Python installation and platform.

---

## **11. Suggested contribution areas**

Software contributions are welcome in areas such as:

- GUI usability and layout
- serial communication robustness
- plotting performance and analysis tools
- packaging and release automation
- Android app development
- documentation and onboarding
- teaching-specific features and exercise support

When opening an issue or pull request, it helps to include:
- operating system
- GUI version or commit hash
- firmware version and board revision
- steps to reproduce
- screenshots, logs, or exported data when relevant

---

## **12. Relationship to the rest of the project**

The `Software` folder works together with the rest of the repository:

- **Hardware** defines the physical Spikeling device
- **Firmware** runs on the ESP32 / ESP32-S3 hardware
- **Software** provides the user interface, control layer, plotting, and export
- **Documentation** explains setup, usage, and teaching workflows

Together, these layers make Spikeling a complete open-source neuroscience teaching platform rather than a standalone board or a standalone app.

---

## **13. License**

Software in this repository is released under the **GNU General Public License v3.0 or later (GPL-3.0-or-later)**.

See:
- [`../LICENSE.txt`](../LICENSE.txt)
- [Repository license information](https://github.com/OpenSourceNeuro/Spikeling)

Hardware files are licensed separately under **CERN-OHL-S-2.0**.

---

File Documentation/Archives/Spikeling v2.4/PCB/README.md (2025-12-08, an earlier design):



<h1 align="center"> Spikeling v2 - Assembly Manual</h1></p>

<br></br>

## Overview

<p align="justify">
This page contains detailed assembly instructions for both version of La Spikeling unit, and includes a parts list for purchasing all electronics components.
Instructions on how to upload and update the microcontroller code and how to calibrate the device can be found <a href="https://github.com/OpenSourceNeuro/Spikeling-V2/tree/main/Instruction%20Manual"> <strong>on the instruction manual</strong> </a>.
Instructions regarding the GUI and on how to design stimuli can be found <a href="https://github.com/OpenSourceNeuro/LED-Zappelin-V2/blob/main/GUI_UserManual.md"><strong>here</strong></a>
</p>

***

- [Ordering PCB](#Ordering-the-PCB)
- [Assembling Spikeling](#Assembly)
- [Acrylic Covers](#Acrylic-Covers)

***

## Ordering the PCB

<p align="justify">
First step consist in getting the printed circuit board (PCB).
The PCB source files were designed on <a href="http://kicad.org/">KiCAD 9.0</a> and are available here to be modified by users if need be.
Users can find the "Gerber" files (zipped in the gerber folder) that companies (i.e. <a href="https://jlcpcb.com">JLCPCB</a>) will request to manufacture PCBs.
</p>

<p >
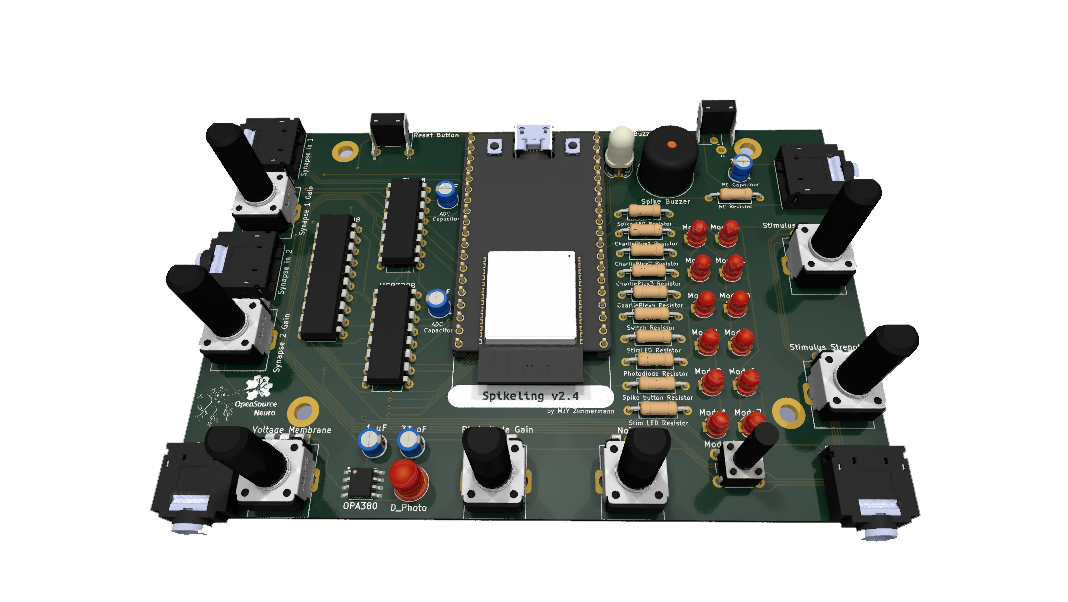
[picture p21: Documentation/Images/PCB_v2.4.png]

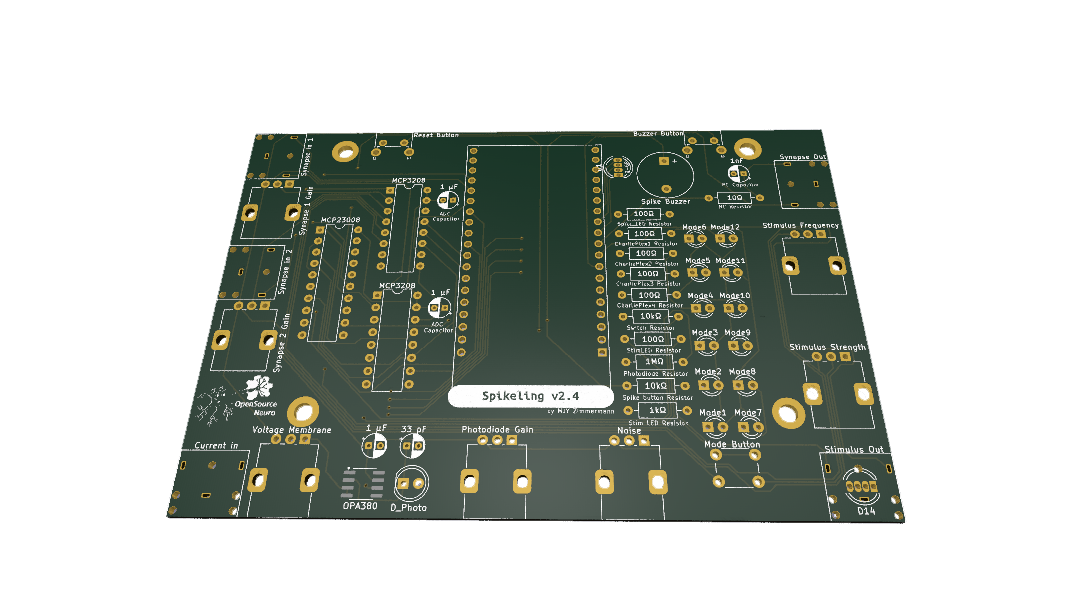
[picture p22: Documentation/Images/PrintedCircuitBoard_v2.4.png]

</p>

<br></br>

***
***

## Assembly

## Acrylic Covers

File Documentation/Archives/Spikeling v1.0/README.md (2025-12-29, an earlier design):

# Welcome to the official Spikeling GitHub

Understanding of how neurons encode and compute information is fundamental to our study of the brain, but opportunities for hands-on experience with neurophysiological techniques on live neurons are scarce in science education. Here, we present Spikeling, an open source £25 in silico implementation of a spiking neuron that mimics a wide range of neuronal behaviours for classroom education and public neuroscience outreach.

For details, please refer to
- the main manuscript on BioRxiv [here](https://www.biorxiv.org/content/early/2018/05/21/327502) 
- the entry on Open Labware [here](https://open-labware.net/projects/spikeling/)

Spikeling in action

Spikeling is based on an Arduino microcontroller running the computationally efficient Izhikevich model of a spiking neuron.  The microcontroller is connected to input ports that simulate synaptic excitation or inhibition, dials controlling current injection and noise levels, a photodiode that makes Spikeling light-sensitive and an LED and speaker that allows spikes to be seen and heard. Output ports provide access to variables such as membrane potential for recording in experiments or digital signals that can be used to excite other connected Spikelings. These features allow for the intuitive exploration of the function of neurons and networks.

# Files

In this repository and the associated publication (linked above) you will find all files needed to build a Spikeling, get started with it and do some basic data analysis.

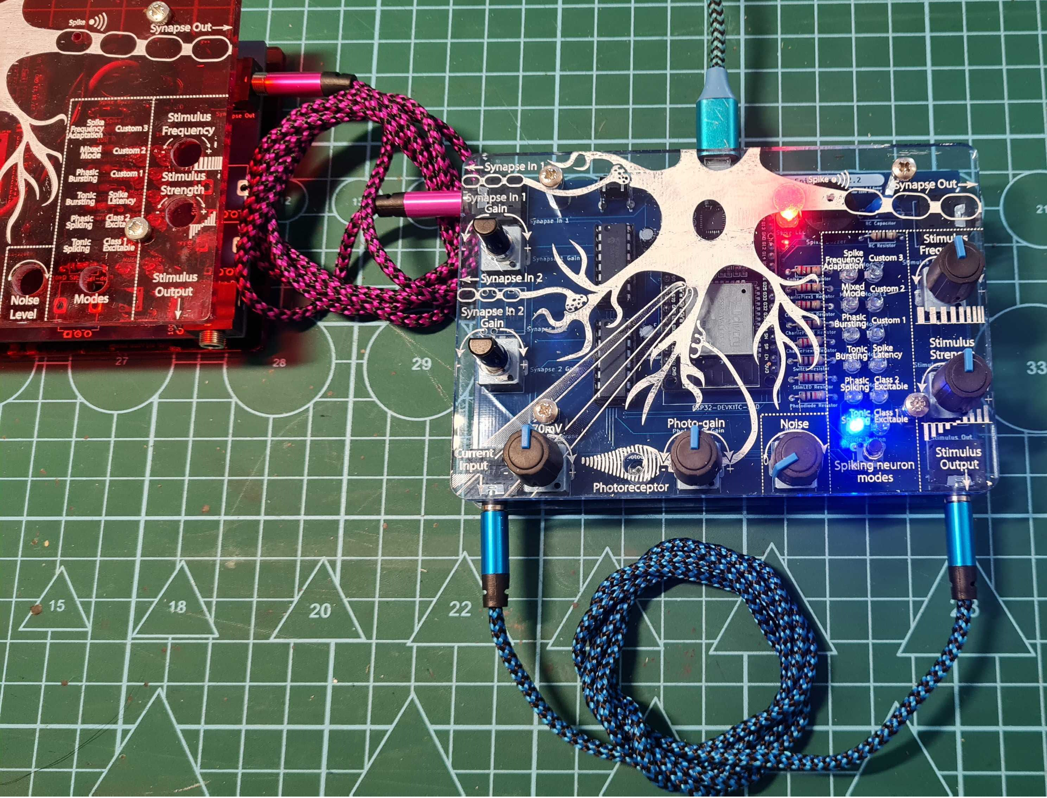
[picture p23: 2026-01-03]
Documentation/Images/Spikeling_hardware.png

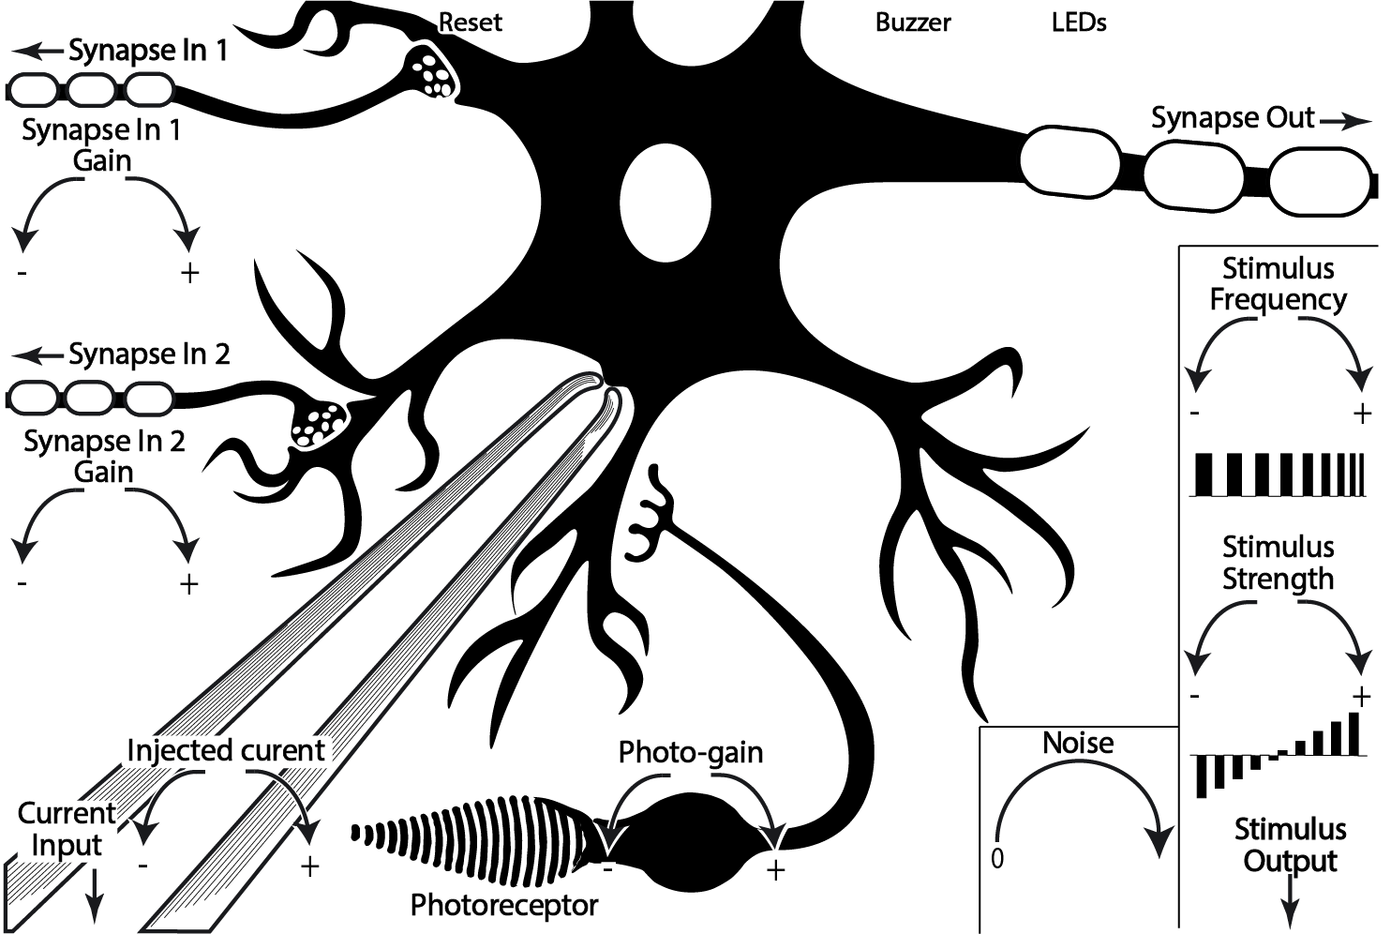
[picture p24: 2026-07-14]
Hardware/Cover/SpikelingV3_CoverFront_Engraving.bmp

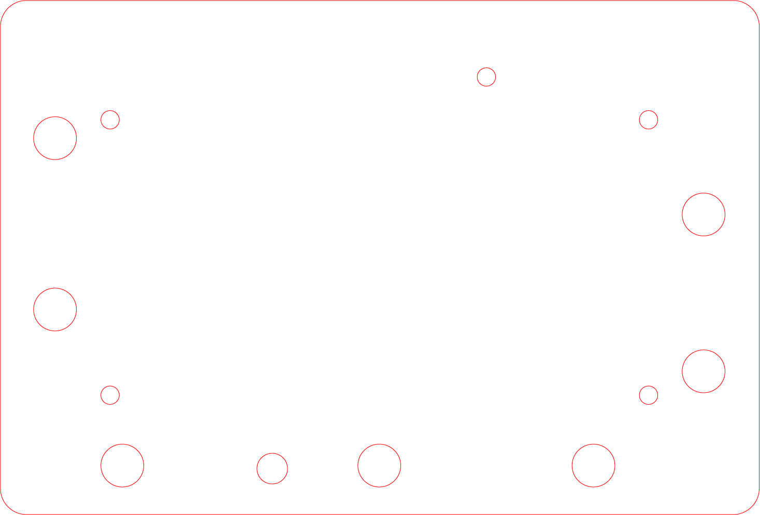
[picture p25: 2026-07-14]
Hardware/Cover/SpikelingV3_CoverFront_Cut.png

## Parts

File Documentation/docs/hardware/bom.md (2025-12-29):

# Bill of materials

TODO: BOM tables, sourcing notes (LCSC/JLC/DigiKey), and part alternatives.

## Core BOM

TODO

## Optional parts

TODO

## Known substitutions

TODO

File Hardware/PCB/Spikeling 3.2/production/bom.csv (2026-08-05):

Designator | Footprint | Quantity | Value | LCSC Part #
B1 | BUZ-TH_L12.0-W12.0 | 1 | 4kHz | C7421651
BT1 | JST_XH_B2B-XH-A_1x02_P2.50mm_Vertical | 1 | Battery_Cell | C265283
C1, C55 | C_0603 | 2 | 1nF | C100040
C10, C12, C13, C18, C21, C23, C27, C28, C3, C30, C32, C33, C35, C37, C39, C42, C44, C45, C47, C49, C51, C53, C56, C57, C58, C6, C60, C62, C64, C8 | C_0603 | 30 | 100nF | C1591
C11, C14, C2, C24, C25, C26, C36, C4, C40, C61 | C_0805 | 10 | 1uF | C28323
C15, C16, C17, C29, C31, C34, C38, C5, C52, C59 | C_0805 | 10 | 4.7uF | C694229
C19, C20, C9 | C_1206 | 3 | 22uF | C12891
C22, C7 | C_1206 | 2 | 10uF | C2171160
C41 | C_0805 | 1 | 10uF | C2932476
C43 | C_0603 | 1 | 4.7nF | C53987
C46, C48, C50, C63 | C_0603 | 4 | 10nF | C100042
C54 | C_0603 | 1 | 10pF | C91367
D1 | D_SOD-123FL | 1 | SMF6.0A | C178260
D10, D12, D19, D6, D7, D9 | SOT-23-3_L2.9-W1.3-P1.90-LS2.4-BR | 6 | BAT54S | C916425
D11, D14, D17, D18, D5, D8 | SC-70-3_L2.0-W1.3-P0.65-LS2.1-BL | 6 | TPD2E2U06DCKR | C1855726
D13 | SENSOR-TH_BPW34S-Z | 1 | BPW34S-Z | C67891
D15 | LED_Kingbright_APFA3010_3x1.5mm_Horizontal | 1 | LED_BGKR
D16 | LED-SMD_4P-L3.2-W2.8-BL | 1 | MHPC3528CRGBCT | C2962096
D2, D3 | D_0603 | 2 | Red | C2286
D4 | D_0603 | 1 | Yellow | C89811
J1 | TYPE-C-SMD_HX-TYPE-C-16PIN | 1 | Connector, USB-TYPE-C-16P | C2927039
J2 | AUDIO-SMD_HX-PJ-320A-3P-DIP | 1 | Synapse1 In | C19189087
J3 | AUDIO-SMD_HX-PJ-320A-3P-DIP | 1 | Synapse2 In | C19189087
J4 | AUDIO-SMD_HX-PJ-320A-3P-DIP | 1 | Input Current | C19189087
J5 | AUDIO-SMD_HX-PJ-320A-3P-DIP | 1 | Stimulus Out | C19189087
J6 | AUDIO-SMD_HX-PJ-320A-3P-DIP | 1 | Synapse Out | C19189087
J7 | AUDIO-SMD_PJ-320B | 1 | Oscilloscope Output | C18594
L1, L5 | L0805 | 2 | BLM21PG221SN1D | C85840
L2 | IND-SMD_L3.0-W3.0_XFL3012 | 1 | 2.2uH | C3911432
L3 | L_0805 | 1 | MPZ2012S601 | C21519
L4 | IND-SMD_L4.4-W4.0_PHC0420 | 1 | 2.2uH | C5349665
Q1 | SOT-23-6_L2.9-W1.6-P0.95-LS2.8-BR | 1 | FS8205A | C908265
Q2, Q3, Q4 | Q_SOT-23 | 3 | 2N7002 | C8545
R1, R16, R18, R24, R61 | R_0603 | 5 | 1MΩ | C105578
R10, R8 | R_0603 | 2 | 5.1MΩ | C227984
R11, R23, R26, R27, R45, R69, R70, R71, R72, R73, R74, R9 | R_0603 | 12 | 100Ω | C115420
R12 | R_0603 | 1 | 2.2kΩ | C4190
R13 | R_0603 | 1 | 330Ω | C23138
R14 | R_0603 | 1 | 910kΩ | C2907075
R15, R17, R19, R20, R21, R31, R32, R33, R34, R48, R49, R53, R54, R59, R67, R77, R80, R81 | R_0603 | 18 | 100kΩ | C14675
R2, R22, R3, R4, R5 | R_0603 | 5 | 5.1kΩ | C23186
R25, R30, R35, R44, R46, R66, R75, R78, R79 | R_0603 | 9 | 10kΩ | C2906982
R28, R29 | R_0603 | 2 | 220Ω | C22962
R36, R37 | R_0603 | 2 | 22Ω | C23345
R38, R39, R40, R41, R42, R43 | R_0603 | 6 | 47Ω | C23182
R47, R50, R51, R52, R55, R56, R57, R58, R60, R62, R63, R64, R65, R76, R82 | R_0603 | 15 | 1kΩ | C2907002
R6 | R_0603 | 1 | 0Ω | C21189
R68 | R_0603 | 1 | 150Ω | C22808
R7 | R_0603 | 1 | 4.7kΩ | C23162
SW1 | SW-TH_K3-1260D-L1 | 1 | K3-1260D-L1 | C92657
SW2 | SW_TS-1088-AR02016 | 1 | Tactile Button, 160gf | C720477
SW3, SW4, SW5 | KEY-TH_4P-L7.5-W6.8-P4.50-LS7.2 | 3 | SKHHLVA010 | C2845277
TP1, TP2, TP3, TP4 | TestPoint_Pad_D2.0mm | 4 | TestPoint
TV1 | SOT-23-6_L2.9-W1.6-P0.95-LS2.8-BR | 1 | SRV05-4-P-T7 | C85364
U1 | F1812 | 1 | MF-MSMF050-2 | C17313
U10, U11 | SOIC-16_L9.9-W3.9-P1.27-LS6.0-BL | 2 | MCP3208T-CI/SL | C626764
U12 | WIFIM-SMD_ESP32-S3-WROOM-1-N8 | 1 | ESP32-S3-WROOM-1-N4 | C2913197
U13 | VSSOP-8_L3.0-W3.0-P0.65-LS4.9-BL | 1 | OPA380AIDGKR | C2057355
U14 | SOT-23-5_L3.0-W1.7-P0.95-LS2.8-BR | 1 | TLV9001IDBVR | C398363
U15 | SOIC-8_L4.9-W3.9-P1.27-LS6.0-BL | 1 | MCP6002T-I/SN | C7377
U2, U8 | SC-70-6_L2.0-W1.3-P0.65-LS2.1-BL | 2 | LM66100DCKR | C2869734
U3 | WSON-8_L2.0-W2.0-P0.50-TL-EP | 1 | TPS62162DSGR | C40256
U4 | SOT-23-5_L2.9-W1.6-P0.95-LS2.8-BR | 1 | TPS7A2033PDBVR | C2862740
U5 | SOT-23-5_L3.0-W1.7-P0.95-LS2.8-BR | 1 | MCP73812T-420I/OT | C144308
U6 | WSON-6_L1.5-W1.5-P0.50-TL | 1 | BQ29700DSER | C183096
U7 | VSON-10_L3.0-W3.0-P0.50-TL-EP_TPS62410DRCR | 1 | TPS61200DRCR | C140320
U9 | SOIC-14_L8.7-W3.9-P1.27-LS6.0-BL | 1 | MCP4922-E/SL | C39851
VR1, VR2, VR3, VR4, VR6, VR7 | RES-TH_RK09D1130C2P | 6 | 10kΩ | C470316
VR5 | RES-TH_RK09D1130C2P | 1 | 10kΩ | C361173

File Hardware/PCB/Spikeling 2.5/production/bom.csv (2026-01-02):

Designator | Footprint | Quantity | Value | LCSC Part #
._2 | Spikeling_Photoreceptor | 1 | Spikeling_neuron
. | Spikeling_Neuron | 1 | Spikeling_neuron
BZ1 | Buzzer_11.5x9.5RM5 | 1 | Spike Buzzer
C1, C2 | CP_Radial_D4.0mm_P2.00mm | 2 | 1 μF
C3 | CP_Radial_D4.0mm_P2.00mm | 1 | 1nF
D1 | LED_D5.0mm-4_RGB_Wide_Pins | 1 | Spike LED
D10 | LED_D3.0mm | 1 | Mode9
D11 | LED_D3.0mm | 1 | Mode10
D12 | LED_D3.0mm | 1 | Mode11
D13 | LED_D3.0mm | 1 | Mode12
D2 | LED_D3.0mm | 1 | Mode1
D3 | LED_D3.0mm | 1 | Mode2
D4 | LED_D3.0mm | 1 | Mode3
D5 | LED_D3.0mm | 1 | Mode4
D6 | LED_D3.0mm | 1 | Mode5
D7 | LED_D3.0mm | 1 | Mode6
D8 | LED_D3.0mm | 1 | Mode7
D9 | LED_D3.0mm | 1 | Mode8
J1 | Spikeling Audio Jack 3.5mm | 1 | Synapse Out
J2 | Spikeling Audio Jack 3.5mm | 1 | Synapse in 1
J3 | Spikeling Audio Jack 3.5mm | 1 | Synapse in 2
J4 | Spikeling Audio Jack 3.5mm | 1 | Current in
J5 | Spikeling Audio Jack 3.5mm | 1 | Stimulus Out
R1 | R_Axial_DIN0207_L6.3mm_D2.5mm_P10.16mm_Horizontal | 1 | 10Ω
R10 | Photoresistor_3.4 | 1 | R_Photo
R11, R2, R5 | R_Axial_DIN0207_L6.3mm_D2.5mm_P10.16mm_Horizontal | 3 | 10kΩ
R3, R4, R6, R7, R8, R9 | R_Axial_DIN0207_L6.3mm_D2.5mm_P10.16mm_Horizontal | 6 | 100Ω
RV1 | Spikeling Potentiometer | 1 | Synapse 1 Gain
RV2 | Spikeling Potentiometer | 1 | Synapse 2 Gain
RV3 | Spikeling Potentiometer | 1 | Voltage Membrane
RV4 | Spikeling Potentiometer | 1 | Noise
RV5 | Spikeling Potentiometer | 1 | Photodiode Gain
RV6 | Spikeling Potentiometer | 1 | Stimulus Strength
RV7 | Spikeling Potentiometer | 1 | Stimulus Frequency
SW1 | SW_PUSH_6mm_H13mm | 1 | Mode Button
SW2 | Spikeling reset button | 1 | Buzzer Button
SW3 | Spikeling reset button | 1 | Reset Button
U1 | MODULE_ESP32-DEVKITC-32D | 1 | ESP32-DEVKITC-32D
U2, U3 | DIP-16_W7.62mm | 2 | MCP3208

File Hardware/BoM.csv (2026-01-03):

Name | Manufacturer | Manufacturer ID | Retailer | Retailer ID | Quantity | Observation 1 | Suggested URL | Cost
ESP32 Dev module | Espressif Systems | ESP32-DEVKITC-VE | Digikey | 1965-ESP32-DEVKITC-VE-ND | 1 |  | https://www.digikey.co.uk/en/products/detail/espressif-systems/ESP32-DEVKITC-VE/12091812
Detent potentiometer | Bourns | PTV09A-4225F-B103 | RS | 827-4990 | 6 | Syn1, Syn2, Vm, PD, Fr, St | https://uk.rs-online.com/web/p/potentiometers/8274990?searchId=22493bc3-c651-455c-9294-958e63f149a7&gb=s
No-detent potentiometer | Bourns | PTV09A-4025F-B103 | RS | 181-4488 | 1 | Noise | https://uk.rs-online.com/web/p/potentiometers/1814488?searchId=5138736d-87d0-4a75-9752-bf8f8f23c40a&gb=s
3.5mm jack connector | RS-Pro | 913-1009 | RS | 913-1009 | 5 |  | https://uk.rs-online.com/web/p/jack-plugs-sockets/9131009?searchId=2c0336f3-d739-40b2-949a-42ff9f557dda&gb=s
Plunger Tactile Switch | Omron | B3F-3120 | RS | 686-6884 | 2 |  | https://uk.rs-online.com/web/p/tactile-switches/6866884?searchId=70f29464-77be-4218-9553-7f822bebb458&gb=s
Tactile Switch | Alps Alpine | SKHHDHA010 | RS | 758-1975 | 1 |  | https://uk.rs-online.com/web/p/tactile-switches/7581975?gb=s
Piezo Buzzer | RS-Pro | 181-2739 | RS | 181-2739 | 1 |  | https://uk.rs-online.com/web/p/piezo-buzzers/1812739?searchId=69850575-7d3e-4b5f-a63a-7f8974e75ec1&gb=s
Photodiode | ams OSRAM | SFH 203 P | RS | 654-8671 | 1 |  | https://uk.rs-online.com/web/p/photodiodes/6548671?searchId=9db1ab38-9fea-4dfe-ad95-fc149c7bcfdf&gb=s
10? Resistor | RS-Pro | 707-7509 | RS | 707-7509 | 1 |  | https://uk.rs-online.com/web/p/through-hole-resistors/7077509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
10k? Resistor | RS-Pro | 707-7745 | RS | 707-7745 | 3 |  | https://uk.rs-online.com/web/p/through-hole-resistors/7077745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
220? Resistor | RS-Pro | 707-7612 | RS | 707-7612 | 5 | Replace the 100?, depending on the top acrylic opacity, adjusting these resistor values modify LEDs brightness
DIP 16 | ASSMANN WSW | A 16-LC-TT | RS | 674-2432 | 2 |  | https://uk.rs-online.com/web/p/dil-sockets/6742432?searchId=86e0a296-b2f8-4870-8640-661f18704577&gb=s
MCP3208 | Microchip | MCP3208-CI/P | RS | 379-2516 | 2 |  | https://uk.rs-online.com/web/p/analogue-to-digital-converters/3792516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
1?F Capacitor | RS-Pro | 711-2103 | RS | 711-2103 | 2 |  | https://uk.rs-online.com/web/p/aluminium-capacitors/7112103?searchId=3bd5c97d-0696-4fca-8943-63c37c72144c&gb=s
1nF Capacitor | Vishay | HVCC153Y6P102KEAX | RS | 204-2380 | 1 |  | https://uk.rs-online.com/web/p/single-layer-ceramic-capacitors/2042380?gb=s
Potentiometer knob | Sifam | 3/03/DR110-006/237/233 | RS | 299-4907 | 7 |  | https://uk.rs-online.com/web/p/potentiometer-knobs/2994907?searchId=1bc9294d-ccd6-49b0-b7ef-d202f5742ca7&gb=s
3mm LED | Kingbright | L-34QBC-D | RS | 862-2872 | 12 | Select any colour relevant or matching the top acrylic
Common Cathode RGB LED | Kingbright | L-154A4SURKQBDZGW | RS | 861-4307 | 1 |  | https://uk.rs-online.com/web/p/leds/8614307?gb=s
M3 x M3 Thread, 5mm Body | RS-Pro | 606-670 | RS | 606-670 | 4 |  | https://uk.rs-online.com/web/p/standoffs/0606670?searchId=bd61539a-c524-4924-a727-4a801f65e7a6&gb=s
M3 x M3 Thread, 10mm Body | RS-Pro | 222-395 | RS | 222-395 | 4 |  | https://uk.rs-online.com/web/p/standoffs/0222395?searchId=7eb9d18b-541a-4336-a950-aaf816f4ba9f&gb=s
Screws DIN 7985, M3x6mm | RS-Pro | 190-428 | RS | 190-428 | 8 |  | https://uk.rs-online.com/web/p/machine-screws/0190428?searchId=1c54ddf7-234e-442e-84dc-f56f64f62ed1&gb=s

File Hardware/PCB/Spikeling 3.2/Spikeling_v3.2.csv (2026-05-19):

Reference | Qty | Value | DNP | Exclude from BOM | Exclude from Board | Footprint
B1 | 1 | 4kHz |  |  |  | Maxime:BUZ-TH_L12.0-W12.0
BT1 | 1 | Battery_Cell |  |  |  | Connector_JST:JST_XH_B2B-XH-A_1x02_P2.50mm_Vertical
C1,C55 | 2 | 1nF |  |  |  | JLCPCB:C_0603
C2,C4,C11,C14,C24,C25,C26,C36,C40,C61 | 10 | 1uF |  |  |  | JLCPCB:C_0805
C3,C6,C8,C10,C12,C13,C18,C21,C23,C27,C28,C30,C32,C33,C35,C37,C39,C42,C44,C45,C47,C49,C51,C53,C56,C57,C58,C60,C62 | 29 | 100nF |  |  |  | JLCPCB:C_0603
C5,C15,C16,C17,C29,C31,C34,C38,C52,C59 | 10 | 4.7uF |  |  |  | JLCPCB:C_0805
C7,C22 | 2 | 10uF |  |  |  | JLCPCB:C_1206
C9,C19,C20 | 3 | 22uF |  |  |  | JLCPCB:C_1206
C41 | 1 | 10uF |  |  |  | JLCPCB:C_0805
C43 | 1 | 4.7nF |  |  |  | JLCPCB:C_0603
C46,C48,C50,C63 | 4 | 10nF |  |  |  | JLCPCB:C_0603
C54 | 1 | 10pF |  |  |  | JLCPCB:C_0603
D1 | 1 | SMF6.0A |  |  |  | JLCPCB:D_SOD-123FL
D2,D3 | 2 | Red |  |  |  | JLCPCB:D_0603
D4 | 1 | Yellow |  |  |  | JLCPCB:D_0603
D5,D8,D11,D14,D17,D18 | 6 | TPD2E2U06DCKR |  |  |  | Maxime:SC-70-3_L2.0-W1.3-P0.65-LS2.1-BL
D6,D7,D9,D10,D12,D19 | 6 | BAT54S |  |  |  | JLCPCB:SOT-23-3_L2.9-W1.3-P1.90-LS2.4-BR
D13 | 1 | BPW34S-Z |  |  |  | Maxime:SENSOR-TH_BPW34S-Z
D15 | 1 | LED_BGKR |  |  |  | LED_SMD:LED_Kingbright_APFA3010_3x1.5mm_Horizontal
D16 | 1 | MHPC3528CRGBCT |  |  |  | Maxime:LED-SMD_4P-L3.2-W2.8-BL
J1 | 1 | Connector, USB-TYPE-C-16P |  |  |  | JLCPCB:TYPE-C-SMD_HX-TYPE-C-16PIN
J2 | 1 | Synapse1 In |  |  |  | Maxime:AUDIO-SMD_HX-PJ-320A-3P-DIP
J3 | 1 | Synapse2 In |  |  |  | Maxime:AUDIO-SMD_HX-PJ-320A-3P-DIP
J4 | 1 | Input Current |  |  |  | Maxime:AUDIO-SMD_HX-PJ-320A-3P-DIP
J5 | 1 | Stimulus Out |  |  |  | Maxime:AUDIO-SMD_HX-PJ-320A-3P-DIP
J6 | 1 | Synapse Out |  |  |  | Maxime:AUDIO-SMD_HX-PJ-320A-3P-DIP
J7 | 1 | Oscilloscope Output |  |  |  | Maxime:AUDIO-SMD_PJ-320B
L1,L5 | 2 | BLM21PG221SN1D |  |  |  | Maxime:L0805
L2 | 1 | 2.2uH |  |  |  | Maxime:IND-SMD_L3.0-W3.0_XFL3012
L3 | 1 | MPZ2012S601 |  |  |  | JLCPCB:L_0805
L4 | 1 | 2.2uH |  |  |  | Maxime:IND-SMD_L4.4-W4.0_PHC0420
Q1 | 1 | FS8205A |  |  |  | Maxime:SOT-23-6_L2.9-W1.6-P0.95-LS2.8-BR
Q2,Q3,Q4 | 3 | 2N7002 |  |  |  | JLCPCB:Q_SOT-23
R1,R16,R18,R24,R61 | 5 | 1MΩ |  |  |  | JLCPCB:R_0603
R2,R3,R4,R5,R22 | 5 | 5.1kΩ |  |  |  | JLCPCB:R_0603
R6 | 1 | 0Ω |  |  |  | JLCPCB:R_0603
R7 | 1 | 4.7kΩ |  |  |  | JLCPCB:R_0603
R8,R10 | 2 | 5.1MΩ |  |  |  | JLCPCB:R_0603
R9,R11,R23,R26,R27,R45,R69,R70,R71,R72,R73,R74 | 12 | 100Ω |  |  |  | JLCPCB:R_0603
R12 | 1 | 2.2kΩ |  |  |  | JLCPCB:R_0603
R13 | 1 | 330Ω |  |  |  | JLCPCB:R_0603
R14 | 1 | 910kΩ |  |  |  | JLCPCB:R_0603
R15,R17,R19,R20,R21,R31,R32,R33,R34,R48,R49,R53,R54,R59,R67,R77,R80,R81 | 18 | 100kΩ |  |  |  | JLCPCB:R_0603
R25,R30,R35,R44,R46,R66,R75,R78,R79 | 9 | 10kΩ |  |  |  | JLCPCB:R_0603
R28,R29 | 2 | 220Ω |  |  |  | JLCPCB:R_0603
R36,R37 | 2 | 22Ω |  |  |  | JLCPCB:R_0603
R38,R39,R40,R41,R42,R43 | 6 | 47Ω |  |  |  | JLCPCB:R_0603
R47,R50,R51,R52,R55,R56,R57,R58,R60,R62,R63,R64,R65,R76,R82 | 15 | 1kΩ |  |  |  | JLCPCB:R_0603
R68 | 1 | 150Ω |  |  |  | JLCPCB:R_0603
SW1 | 1 | K3-1260D-L1 |  |  |  | Maxime:SW-TH_K3-1260D-L1
SW2 | 1 | Tactile Button, 160gf |  |  |  | JLCPCB:SW_TS-1088-AR02016
SW3,SW4,SW5 | 3 | SKHHLVA010 |  |  |  | Maxime:KEY-TH_4P-L7.5-W6.8-P4.50-LS7.2
TP1,TP2,TP3,TP4 | 4 | TestPoint |  |  |  | TestPoint:TestPoint_Pad_D2.0mm
TV1 | 1 | SRV05-4-P-T7 |  |  |  | JLCPCB:SOT-23-6_L2.9-W1.6-P0.95-LS2.8-BR
U1 | 1 | MF-MSMF050-2 |  |  |  | Maxime:F1812
U2,U8 | 2 | LM66100DCKR |  |  |  | Maxime:SC-70-6_L2.0-W1.3-P0.65-LS2.1-BL
U3 | 1 | TPS62162DSGR |  |  |  | Maxime:WSON-8_L2.0-W2.0-P0.50-TL-EP
U4 | 1 | TPS7A2033PDBVR |  |  |  | Maxime:SOT-23-5_L2.9-W1.6-P0.95-LS2.8-BR
U5 | 1 | MCP73812T-420I/OT |  |  |  | Maxime:SOT-23-5_L3.0-W1.7-P0.95-LS2.8-BR
U6 | 1 | BQ29700DSER |  |  |  | Maxime:WSON-6_L1.5-W1.5-P0.50-TL
U7 | 1 | TPS61200DRCR |  |  |  | Maxime:VSON-10_L3.0-W3.0-P0.50-TL-EP_TPS62410DRCR
U9 | 1 | MCP4922-E/SL |  |  |  | Maxime:SOIC-14_L8.7-W3.9-P1.27-LS6.0-BL
U10,U11 | 2 | MCP3208T-CI/SL |  |  |  | Maxime:SOIC-16_L9.9-W3.9-P1.27-LS6.0-BL
U12 | 1 | ESP32-S3-WROOM-1-N4 |  |  |  | Maxime:WIFIM-SMD_ESP32-S3-WROOM-1-N8
U13 | 1 | OPA380AIDGKR |  |  |  | Maxime:VSSOP-8_L3.0-W3.0-P0.65-LS4.9-BL
U14 | 1 | TLV9001IDBVR |  |  |  | JLCPCB:SOT-23-5_L3.0-W1.7-P0.95-LS2.8-BR
U15 | 1 | MCP6002T-I/SN |  |  |  | JLCPCB:SOIC-8_L4.9-W3.9-P1.27-LS6.0-BL
VR1,VR2,VR3,VR4,VR5,VR6,VR7 | 7 | 10kΩ |  |  |  | Maxime:RES-TH_RK09D1130C2P

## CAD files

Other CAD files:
Hardware/Cover/SpikelingV3_CoverFront_Cut.dxf
Documentation/Archives/Spikeling v1.0/3D print/Spikeling LED holder.scad
Hardware/Cover/SpikelingV3_CoverFront_Cut.dwg

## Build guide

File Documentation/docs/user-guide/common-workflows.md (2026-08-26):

# **Common workflows**

This page collects a set of high-frequency “how people actually use Spikeling” workflows. Each workflow is written to be:

- **quick to scan**
- **reproducible** (clear start state, clear steps)
- **teaching-friendly** (what students should notice and conclude)

If you are new, start with: **Quickstart → First experiment** and return here when you want structured protocols.

See also:
- [Concepts](concepts.md)
- [Device overview](device-overview.md)
- [Recording and export](recording-and-export.md)
- [Experiments](../experiments/index.md)

---

## **Workflow 1 — Connect, verify signal, and set a baseline**

**Goal:** confirm the device/emulator is behaving and Vm is readable.

1. **Connect** hardware (or start emulator).
2. In the Neuron Interface plot, enable:
   - **Vm**
   - **Total Current Input** (if available)
   - **Stimulus** (if you will use it)
3. Confirm Vm shows a stable baseline (no drift, no clipping).
4. Use the **current injection** (hardware knob or patch clamp slider) to bring Vm:
   - below threshold (silent), then
   - close to threshold (occasional spikes), then
   - above threshold (sustained spiking)

**What to look for**
- Vm should change smoothly with injected current.
- Spikes should appear only once threshold is crossed.
- Spike feedback (LED/buzzer) should match the trace (hardware).

---

## **Workflow 2 — Find threshold and demonstrate excitability**

**Goal:** teach “below threshold vs above threshold” clearly.

1. Start from **0 injected current** (centre detent / patch clamp neutral).
2. Increase injected current slowly until spikes appear.
3. Reduce slightly until spikes stop again.

**What to look for**
- A small change in input can switch the system from silent to spiking.
- Near threshold, noise and small fluctuations matter.

**Teaching prompt**
- “What changes qualitatively when threshold is crossed?”

---

## **Workflow 3 — Spike-frequency adaptation under constant drive**

**Goal:** show that firing rate can change even when the input is constant.

1. Inject enough current to produce sustained spiking.
2. Hold the injection steady for several seconds.
3. Observe whether the spike rate slows down.

**Optional quantification**
- Record 10–20 seconds.
- Compute firing rate in early vs late window.
- Summarise as adaptation strength.

**Teaching prompt**
- “Why might a neuron reduce its firing over time under constant input?”

---

## **Workflow 4 — F–I curve (firing rate vs injected current)**

**Goal:** replicate a classic current-clamp characterisation.

1. Choose one neuron mode and keep it fixed.
2. Apply a series of current steps (manual or GUI Steps stimulus).
3. For each step level, measure mean firing rate.
4. Plot firing rate vs input level.

**What to look for**
- threshold-like onset of firing
- gain (slope) changes across modes
- adaptation can create differences between “early rate” and “late rate”

See also: [Experiments → Excitability and threshold](../experiments/excitability-and-threshold.md)

---

## **Workflow 5 — Use the stimulus output as injected current**

**Goal:** use the GUI stimulus generator as a function generator for current injection.

1. Patch a cable:
   - **Stimulus output → DC/current injection input**
2. In the GUI, choose a stimulus type (Steps is best to start).
3. Increase stimulus strength slowly while watching Vm.

**What to look for**
- Vm follows the stimulus time-course.
- spikes align with stimulus epochs (especially for steps/pulses).

**Teaching prompt**
- “How does waveform shape change spiking compared to constant DC injection?”

---

## **Workflow 6 — Square-wave stimulation: frequency vs strength**

**Goal:** teach how two intuitive stimulus knobs affect output.

1. Use the **on-board square stimulus** (or GUI square/pulse train).
2. Sweep **strength** at fixed frequency.
3. Sweep **frequency** at fixed strength.

**What to look for**
- strength controls recruitment into spiking and spike reliability
- frequency determines how often depolarising drive is applied (and may push the neuron into different regimes)

---

## **Workflow 7 — Noise near threshold (stochastic spiking)**

**Goal:** show why spiking can be probabilistic.

1. Set injected current so Vm sits **just below threshold** (no spikes).
2. Increase **Noise** gradually.
3. Observe occasional spikes emerge without changing the mean input.

**What to look for**
- variability and spike-time jitter
- spikes occur at unpredictable times, but rate increases with noise amplitude

**Teaching prompt**
- “Why does the same mean input produce different outcomes when noise is present?”

---

## **Workflow 8 — Light stimulation (photoreceptor pathway)**

**Goal:** demonstrate sensory stimulation logic: light input → Vm/spikes.

**Two common setups**
- **Controlled LED pathway:** Stimulus output → LED cable → photodiode
- **External light:** any modulated LED/light source aimed at the photodiode

**Workflow**
1. Set **Photo-gain** to a modest value.
2. Deliver light pulses or flicker.
3. Invert gain sign to show excitatory vs inhibitory sensory drive.

**What to look for**
- polarity matters: same light can depolarise or hyperpolarise depending on gain sign
- photoreceptor dynamics (decay/recovery) shape responses to rapid flicker

---

## **Workflow 9 — Two-unit network: Axon → Synapse**

**Goal:** teach synaptic integration and E/I coupling.

1. Connect:
   - **Axon output (unit A) → Synapse input (unit B)**
2. Make unit A spike (inject current).
3. Adjust Synapse gain on unit B:
   - positive = excitatory
   - negative = inhibitory

**What to look for**
- spike-evoked synaptic currents with exponential decay
- summation across repeated presynaptic spikes
- recruitment or suppression of postsynaptic firing

See also:
- [Experiments → Synapses and inputs](../experiments/synapses-and-inputs.md)
- [Experiments → Network with two units](../experiments/network-two-units.md)

---

## **Workflow 10 — Emulator: build a network without cables**

**Goal:** teach network logic in a reproducible environment.

1. Start emulator.
2. Configure **Auxiliary Neuron 1** to spike.
3. Toggle **Synapse main neuron**.
4. Set synapse sign/gain (Synapse 1 or 2).
5. Observe main neuron recruitment / suppression.

This workflow is ideal for large classes where not every student has two physical units.

---

## **Workflow 11 — Record, export, and analyse (minimal pipeline)**

**Goal:** produce a clean dataset students can analyse.

1. Choose a simple protocol (Steps or square stimulation).
2. Record 10–30 seconds.
3. Export CSV.
4. Analyse:
   - Vm trace
   - stimulus/current trace
   - spike detection and rate
   - optionally: F–I curve or adaptation index

See also:
- [Recording and export](recording-and-export.md)
- [Data analysis → Python quickstart](../data-analysis/python-quickstart.md)

---

## **Workflow 12 — Classroom-ready “demo sequence” (3 minutes)**

If you need a fast outreach demonstration:

1. Inject current to show silent → spiking transition.
2. Turn up noise near threshold for stochastic spikes.
3. Switch neuron mode and repeat (same input, different output).
4. Optional: connect a second unit and show synaptic recruitment.

---

## **What to read next**

- Structured protocols with expected outcomes: [Experiments](../experiments/index.md)
- Curriculum modules and teaching resources: [Teaching Hub](../teaching-hub/index.md)
- If you want analysis templates: [Data analysis](../data-analysis/index.md)

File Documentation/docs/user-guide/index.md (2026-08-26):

# **User guide**

This section explains how to **use Spikeling day-to-day**: what the signals mean, how the hardware inputs/outputs map to the GUI, how to record/export data, and how to run common classroom workflows.

If you are still setting up the device (drivers, firmware, first connection), start with **[Quickstart](../quickstart/index.md)**.

---

## **What you will learn here**

By working through the User guide you will be able to:

- interpret the main traces (**Vm**, **total input current**, stimulus, synaptic channels)
- understand how inputs (current, stimulus, light, synapses, noise) combine to drive the neuron
- use the GUI efficiently (neuron modes, parameter panels, stimulus tools, patch clamp control)
- record sessions and export clean CSV files for analysis
- use emulator mode for teaching, development, and reproducible demonstrations
- apply common workflows (threshold, F–I curves, adaptation, sensory stimulation, synaptic integration)

---

## **Recommended reading order**

If you are new, follow this sequence once. After that, use the pages as reference while running labs.

1. **[Concepts](concepts.md)**  
   The minimum neuroscience concepts needed to use Spikeling effectively (current clamp logic, threshold, adaptation, synapses, noise, light pathway).

2. **[Device overview](device-overview.md)**  
   What is on the board, what each control affects, and how signals flow from inputs to outputs.

3. **[Controls and I/O](controls-and-io.md)**  
   TRS (3.5 mm) connectors, cable conventions, and the three most common wiring patterns:
   stimulus → LED/photodiode, stimulus → current injection, axon → synapse.

4. **[GUI overview](gui-overview.md)**  
   How to navigate the interface, configure neuron modes, use the right-hand parameter panel (including patch clamp), and manage recording.

5. **[Recording and export](recording-and-export.md)**  
   How to record reliably, what is inside the CSV file, and how to avoid common logging mistakes.

Then continue with the two “bridge” topics:

- **[Fluorescence imaging simulation](fluorescence-imaging-sim.md)**  
  Connect Vm dynamics to calcium/fluorescence-style readouts used in imaging.

- **[Emulator mode](emulator-mode.md)**  
  Use Spikeling without hardware, teach remotely, and emulate network interactions.

Finally, use the task-oriented reference:

- **[Common workflows](common-workflows.md)**  
  High-frequency workflows written as reproducible mini-protocols (threshold, F–I, adaptation, noise, light input, synapses, networks, record → analyse).

---

## **When to use emulator vs hardware**

- Use **hardware** when you want the full physical experience: knobs, cables, LED/buzzer feedback, and real classroom variability.
- Use **emulator mode** when you want a controlled baseline for teaching, rapid iteration, and demonstrations without devices.

---

## **Where to go next**

- Ready-to-run protocols with expected outcomes: **[Experiments](../experiments/index.md)**
- Teaching resources (curriculum catalogue, course pathways and class preparation): **[Teaching Hub](../teaching-hub/index.md)**
- Data analysis starter workflows: **[Data analysis](../data-analysis/index.md)**

---

## **Quick help**

- If something looks wrong in the traces, start with **[Quickstart → Troubleshooting](../quickstart/troubleshooting.md)**.
- If you are teaching a large group, consider starting with **[Emulator mode](emulator-mode.md)** for a consistent baseline before introducing hardware variability.

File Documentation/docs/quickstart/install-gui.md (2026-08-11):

# **Install the GUI**

This page explains how to install and run the Spikeling desktop GUI. The GUI is used to connect to Spikeling hardware (or the emulator), visualize signals in real time, run protocols, and record/export data.

## **Choose an installation method**

There are two common ways to install the GUI:

1. **Install from a pre-built release (recommended for most users)**  
   Best for teaching, outreach, and classroom use.

2. **Install from source (recommended for developers and contributors)**  
   Best if you want to modify the GUI, test changes, or run the latest code from the repository.

---

## **Option A — Install from a pre-built release (recommended)**

If you have a packaged GUI release (installer or pre-built application):

Use **[Latest GUI release](https://github.com/OpenSourceNeuro/Spikeling/releases/latest)** to find GitHub's most recently published release, or browse **[All GUI releases](https://github.com/OpenSourceNeuro/Spikeling/releases)** to select a specific version. "Latest" means newest publication; it does not by itself confirm compatibility with your hardware and firmware. For managed teaching deployments, use the version approved for your equipment.

1. Download the clearly versioned asset for your operating system.
2. Extract / install it.
3. Launch the application.

### **First-run checklist**

- The GUI opens without errors.
- You can open the **Port / Connection** menu and see a list of serial ports.
- If you are using Spikeling hardware:
  - **v2.x**: you installed the **CP210x driver** and the board appears as a COM/serial port.
  - **v3.x**: the board appears as a USB serial device (typically no driver needed).

If the GUI launches but the device does not appear, see **[Troubleshooting](troubleshooting.md)**.

---

## **Option B — Install from source (developers)**

This option runs the GUI using Python. It is cross-platform and convenient for development, but requires installing dependencies.

### **1) Prerequisites**

- **Python 3.10+** (recommended)
- **Git** (recommended)
- (Optional) A virtual environment to isolate dependencies

### **2) Get the source code**

Clone the repository and enter it:

```
git clone https://github.com/OpenSourceNeuro/Spikeling.git
cd Spikeling
```

### **3) Create and activate a virtual environment**

Windows (PowerShell):

```
py -m venv .venv
.\.venv\Scripts\Activate.ps1
```

macOS / Linux:

```
python3 -m venv .venv
source .venv/bin/activate
```

### **4) Install dependencies**

Install from the project `requirements.txt`:

```
pip install -r requirements.txt
```

For reference, the GUI depends on the following pinned versions:

- PySide6==6.9.2
- numpy==2.3.2
- pandas==2.3.2
- pyinstaller==6.15
- pyqtgraph==0.13.7
- scipy==1.16.1

### **5) Run the GUI**

Run the GUI entry point used by the repository (a common pattern is `main.py`):

```
python main.py
```

If your GUI lives in a subfolder (for example `GUI/`), run it from there:

```
cd GUI
python main.py
```

---

## **Verify the GUI is working**

### **Connect to hardware**

1. Plug in your Spikeling board and confirm the serial port is visible (see **[Hardware setup](hardware-setup.md)**).
2. In the GUI, select the correct port and connect.
3. Run a basic stimulus and confirm you see live Vm data.

### **Use emulator mode (no hardware)**

1. Switch the GUI to **Emulator** mode.
2. Start the simulation.
3. Confirm plots update smoothly and recording/export works.

---

## **Common issues**

### **The GUI does not start**

- Confirm your Python version is supported.
- If using a virtual environment, confirm it is activated.
- Reinstall dependencies:

```
pip install -r requirements.txt
```

### **No ports appear / cannot connect**

- **v2.x**: confirm CP210x driver installation and use a known-good USB data cable.
- **v3.x**: try a different USB-C data cable and port.
- Close Arduino Serial Monitor and any serial terminal that might own the port.

See **[Troubleshooting](troubleshooting.md)** for step-by-step triage.

---

## **Next steps**

- If you need to update firmware: **[Flash firmware](flash-firmware.md)**
- Run your first protocol: **[First experiment](first-experiment.md)**

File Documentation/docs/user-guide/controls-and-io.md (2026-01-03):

# **Controls and I/O**

This page explains how Spikeling’s physical connections work: what each connector carries, how to cable units together, and how to avoid the most common wiring mistakes.

Spikeling uses **3.5 mm TRS (stereo) jacks** throughout. The same cable type can carry both an analogue signal and a digital event marker, plus ground.

If you want a high-level tour of the board and controls, see: [Device overview](device-overview.md).

---

## **The TRS convention (Tip / Ring / Sleeve)**

Each Spikeling TRS jack carries:

- **Tip (T)**: **digital** signal (spike events / PWM)
- **Ring (R)**: **analogue** signal (typically Vm or stimulus analogue waveform, depending on jack)
- **Sleeve (S)**: **ground** (0 V reference)

This design lets you carry the information needed for most electrophysiology-style teaching tasks in a single cable: an analogue trace and a digital timing marker.

!!! important "Ground matters"
    The sleeve is not optional. Most “mystery noise” and “flat line” issues happen when the ground reference is missing, intermittent, or swapped.

---

## **What “digital” means on Spikeling**

The **digital** line (Tip) is used for event timing:

- spike events (axon output / synaptic inputs)
- stimulus PWM (pulse width modulation) for LED stimulation
- synchronisation between recordings or units

Digital events are especially useful when analysing data later: they allow you to align traces to a stimulus onset or to detect presynaptic spike timing precisely.

---

## **What “analogue” means on Spikeling**

The **analogue** line (Ring) carries a continuously varying voltage representing one of:

- **Vm** (membrane potential output, read by a second unit or by an oscilloscope mapping to 3.3v)
- **stimulus waveform** (generated by the board or GUI, meant to be plugged on the current input port. External waveform generator mapping current to 3.3v can also be used)

Analogue is what you look at as a trace in the GUI (and later in CSV).

---

## **Connector roles (conceptual map)**

The exact jack labels may vary slightly by revision/board silkscreen, but the roles are consistent:

### **Outputs**

- **Synaptic output**: analogue = Vm (-110 - 100mV -- 0 - 3.3v); digital = spike events
- **Stimulus output**: analogue = stimulus waveform (-100 - 100% -- 0 - 3.3v); digital = Stimulus PWM (12bits)

### **Inputs**

- **Synapse input 1 / 2**: accepts a TRS feed from another unit’s axon output  
  (analogue = Vm; digital = spike events)
- **Current input**: accepts an analogue waveform used as injected current drive
- **Photodiode**: not a connector itself, but a physical input driven by light (often using the LED cable)

---

## **Common cabling patterns (what users actually do)**

### **1) Make a two-unit network (presynaptic → postsynaptic)**

**Goal:** Use one Spikeling unit to drive another via a synapse.

**Cable:**
- Unit A **Axon output** → Unit B **Synapse input 1** (or 2)

**What travels on the TRS:**
- Tip: spike events (trigger synaptic currents)
- Ring: presynaptic Vm (used for visualisation only)
- Sleeve: shared ground reference

Then set the **Synapse gain** (±) on unit B:
- positive = excitatory
- negative = inhibitory

(See also: [Synapses and inputs](../experiments/synapses-and-inputs.md) and [Network with two units](../experiments/network-two-units.md).)

---

### **2) Controlled “visual stimulus” using the LED cable (recommended)**

**Goal:** Deliver reproducible light stimulation to the photodiode as a retina-inspired sensory pathway.

**Cable:**
- **Stimulus output** → **LED cable** → aim LED at **photodiode**

The LED cable lets you use either:
- the **on-board square stimulus** (frequency/strength knobs), or
- the **GUI stimulus generator** (steps, sine, chirps, noise, etc.)

to drive the LED with precise timing.

Then use the **Photo-gain** potentiometer to set:
- magnitude of the photodiode pathway
- polarity (positive vs negative sensory drive)

---

### **3) Use the stimulus output as injected current (stimulus → DC input)**

**Goal:** Treat the stimulus generator like a function generator for injected current.

**Cable:**
- **Stimulus output** → **Current injection / DC input**

This is useful when teaching protocols such as:
- steps (baseline → constant injection → baseline)
- oscillatory drive (sine/triangle)
- sweeps (chirps / ZAP-style probing)
- noise injection (controlled variability)

---

## **Cable and adapter recommendations**

### **Use real stereo (TRS) cables**

Use **3.5 mm stereo TRS** male–male cables (two black rings on the plug).

Avoid:
- mono TS cables (one ring) if you expect both digital + analogue
- TRRS headset cables (three rings), which can map contacts differently

### **Keep cables short when teaching**

Short cables reduce pickup and make demonstrations more stable.

### **Label your classroom cables**

For teaching at scale, label cables by function:
- “AXON → SYN”
- “STIM → LED”
- “STIM → DC”

This saves a lot of time during labs.

---

## **Quick troubleshooting (I/O specific)**

### **“No signal / flat line”**
- confirm you are using a **TRS stereo cable**
- check the plug is fully seated (TRS jacks can feel “in” before they click)
- confirm the correct port (axon vs synapse vs stimulus vs DC)

### **“Signal looks noisy / unstable”**
- confirm **ground (Sleeve)** is present and not intermittent
- shorten cables
- keep LED cables away from analogue signal cables if possible

### **“Synapse does nothing”**
- check you connected **axon output → synapse input**
- confirm the presynaptic unit is actually spiking (LED/buzzer helps)
- increase synapse gain magnitude and confirm polarity (±)

---

## **What to read next**

- Device layout, controls, and revision differences: [Device overview](device-overview.md)
- How signals appear in the GUI: [GUI overview](gui-overview.md)
- Recording and CSV export: [Recording and export](recording-and-export.md)

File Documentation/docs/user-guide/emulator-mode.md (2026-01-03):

# **Emulator mode**

Spikeling includes a built-in **software emulator** that behaves like the hardware from the user’s point of view: you apply inputs, observe **Vm** and **spikes**, and record to CSV.

Emulator mode is designed for:

- **Teaching without devices** (classroom demos, remote workshops, preparation)
- **Developing stimuli/workflows** without needing a board plugged in
- **Troubleshooting** (to separate “GUI issue” from “hardware/serial issue”)
- **Exploring network logic** (synapses) in a controlled, reproducible setup

---

## **What emulator mode reproduces**

Emulator mode mirrors the same conceptual blocks as the physical device:

- **Neuron model behaviour** (Vm dynamics, threshold, spiking, adaptation)
- **Current-clamp style control** (inject current and read Vm)
- **Stimulus generation** (with options to route the stimulus as current or as light)
- **Noise-driven variability**
- **Synapses** (excitatory/inhibitory sign and strength, exponential decay)
- **Recording/export** to CSV in the same spirit as hardware recordings

It is not intended as a biophysically detailed simulator; the goal is to support the **teaching workflow** and the **interpretation skills** used in electrophysiology-style experiments.

---

## **How to start the emulator**

1. In the left navigation, open **Neuron Emulator**.
2. Click **Start Spikeling Emulator** (this is a toggle button).
3. You should see Vm update in the main plot area once the emulator is running.

!!! tip "If nothing moves"
    - Confirm **Start Spikeling Emulator** is enabled (toggled on).  
    - If plots still appear static, change the **Speed** slider slightly, then return it to a mid setting.

---

## **Interface layout (what to look at first)**

Emulator mode uses the same “read the traces, then adjust inputs” teaching loop:

- **Main trace area**: where you watch **Vm** (and other signals depending on your GUI view).
- **Right-hand parameter panel**: where you configure inputs and neuron settings.
- **Four parameter pages** (buttons at the top of the parameter panel):
  - **Neuron Parameters**
  - **Stimulus Parameters**
  - **Synapse 1 Parameters**
  - **Synapse 2 Parameters**
- A **Hide Parameters** button collapses the parameter panel when you want maximum plot space.

---

## **Neuron mode selection (model “modes”)**

Near the top of the emulator controls you can set:

- **Neuron Mode:** (dropdown list)
- **Browse:** (load a mode definition from file)
- **Apply:** (apply the selected/loaded mode)

Use this to demonstrate how different parameter sets (Izhikevich-style **modes**) change excitability and firing pattern under identical input.

!!! note
    For teaching, keep the stimulus fixed and only change mode. Students will see that intrinsic dynamics matter, not just the input waveform.

---

## **Neuron Parameters (inputs and coupling)**

This page controls the core input pathways that shape Vm.

### **Patch clamp (direct current injection)**

The emulator includes a **Patch clamp** control representing direct injected current (current clamp logic).

Typical use:

- Move the patch clamp control to shift Vm from silent → depolarised → spiking → adapting.

### **Noise**

Noise adds variability to the input drive and is the fastest way to demonstrate:

- near-threshold **stochastic spiking**
- spike-time **jitter**
- trial-to-trial variability even under “same” conditions

### **Synapses (network inputs)**

The emulator supports **two synaptic inputs** (Synapse 1 and Synapse 2), mirroring the hardware concept:

- presynaptic spikes generate an **exponentially decaying synaptic current**
- **Synaptic Gain** determines excitatory (positive) vs inhibitory (negative) effect
- **Synaptic Decay** controls how long the synaptic current persists

This enables classic demonstrations:

- summation of synaptic events
- competition between excitation and inhibition
- “one neuron driving another” network logic

---

## **Stimulus Parameters (waveform routing and settings)**

This page controls the emulator’s stimulus generator and how it is applied.

### **Enable/disable and Route the stimulus: Current vs Light**

You can choose whether the stimulus drives:

- **Current** (inject waveform as current), or
- **Light** (treat stimulus as a light-modulated input pathway)

Use the toggle buttons to enable the stimulus pathway.

This is useful pedagogically because it separates:

- “what waveform did I generate?”
from
- “which input pathway did I stimulate?”

### **Frequency and strength**

The stimulus controls include:

- **Frequency** (how fast the waveform repeats / oscillates, depending on mode)
- **Strength** (amplitude)

Use these to build intuition about input–output gain and spike recruitment.

### **Custom stimuli**

If you enable **Custom stimulus**, the emulator can use user-defined waveforms (useful for structured labs and for designing new protocols).

### **Photo-Receptor (photodiode / light pathway parameters)**

When the stimulus is routed to **Light**, the emulator exposes a **Photo-Receptor** block that models how light is converted into an effective input drive for the neuron.

This block has three key controls:

- **Photo-Gain (%)**  
Sets the strength (and sign) of the light-to-drive conversion.
  - **Positive gain**: more light produces a **depolarising** drive (Vm tends to rise)
  - **Negative gain**: more light produces a **hyperpolarising/inhibitory** drive (Vm tends to fall)

- **Photo Decay: λ (ms⁻¹)**  
  Controls how fast the light-driven response **decays** after a light change.
  - Higher λ (towards *Fast*) → quicker decay (shorter, sharper transients)
  - Lower λ (towards *Slow*) → longer decay (more sustained effect)

- **Photo Recovery: λ (ms⁻¹)**  
  Controls how fast the photo-receptor response **recovers** back to baseline and is ready to respond again.
  - Higher λ (towards *Fast*) → faster recovery (tracks rapid flicker better)
  - Lower λ (towards *Slow*) → slower recovery (adaptation-like behaviour)

!!! tip "Teaching tip"
    Use a flickering light stimulus (or a square-wave stimulus routed to **Light**) and vary **Decay** and **Recovery**:
    - fast decay + fast recovery → the response follows rapid flicker more cleanly
    - slow decay → responses overlap and integrate over time
    - slow recovery → the system behaves as if it “adapts” and becomes less responsive to repeated flashes

---

## **Emulating networks (multi-unit coupling in the GUI)**

Emulator mode can simulate **two-unit network interactions** without any physical cables by running an **auxiliary neuron** alongside the main Spikeling neuron and routing its output as a synaptic drive.

This is the cleanest way to teach core network concepts (E/I coupling, synaptic filtering, recruitment into spiking) in a fully reproducible setup.

---

### **How the GUI represents a two-neuron network**

In emulator mode, you typically have:

- a **Main neuron** (the one displayed as “Spikeling” in the plot)
- Two **Auxiliary neurons**

Auxiliary neurons can be configured to send its spikes/Vm into the main neuron through a *virtual* synapse.

In the right-hand panel (Auxiliary Neuron #), you will see:

- **Neuron Mode** (dropdown + Browse + Apply)
- **Synapse main neuron** (toggle)
- **Patch Clamp** (Injected Current)
- **Noise** (Noise Level)
- **Stimulus** routing and **Photo-Receptor** parameters (if using light stimulation logic)

---

### **Step-by-step: create a simple 2-neuron network**

1. **Start the emulator** and ensure the main neuron Vm is updating.

2. Open **Auxiliary Neuron 1** parameter panel.

3. Set the auxiliary neuron’s **Neuron Mode** and click **Apply**  
   Choose a mode that spikes reliably (tonic spiking is the easiest to start with).

4. Drive the auxiliary neuron to spike using **Patch Clamp**  
   Increase injected current until you see stable spiking in the auxiliary neuron trace (if displayed).

5. Enable coupling: toggle **Synapse main neuron**  
   This routes the auxiliary neuron’s output into the main neuron as a synaptic input.

6. In **Neuron Parameters**, configure the synaptic effect using **Synapse 1** or **Synapse 2** panel  
   Use the synapse gain/sign (sets to 0 by default so synaptic input has no effect on the main spikeling by default) controls to set:
   - **excitatory** coupling (positive gain: auxiliary spikes depolarise the main neuron)
   - **inhibitory** coupling (negative gain: auxiliary spikes hyperpolarise/suppress the main neuron)

7. Observe the main neuron:
   - Does synaptic input recruit spikes?
   - Does inhibition silence spiking?
   - Does the main neuron show temporal summation (multiple presynaptic spikes accumulate)?

---

### **What to teach with this (high-value network demonstrations)**

#### **1) Excitatory drive: “one neuron makes another fire”**
- Make Auxiliary Neuron 1 spike regularly (Patch Clamp).
- Set Synapse gain **positive**.
- Watch the main neuron depolarise and (often) begin spiking even if its own injected current is low.

Teaching questions:
- “What happens if I halve the synapse gain?”
- “How many presynaptic spikes are needed to trigger a postsynaptic spike?”

#### **2) Inhibitory control: vetoing spiking**
- Keep the main neuron just above threshold (so it would normally spike).
- Enable auxiliary neuron coupling with **negative** synapse gain.
- Increase auxiliary firing rate and observe suppression / spike skipping.

Teaching questions:
- “Can inhibition completely silence the neuron?”
- “How does inhibition change spike timing reliability?”

#### **3) Temporal filtering (synaptic decay)**
Use synapse decay parameters (where available in Synapse panels) to show:
- fast decay: brief, well-separated postsynaptic effects
- slow decay: integration over time (more summation)

Teaching questions:
- “Why does slow synapse decay promote integration?”
- “Why does fast decay make timing more precise?”

#### **4) Noise + synapses: variability in networks**
- Hold the main neuron just below threshold.
- Turn on auxiliary synaptic input and add a small amount of noise.
- Show probabilistic recruitment: sometimes spikes occur, sometimes they do not.

Teaching question:
- “Why can two identical synaptic events produce different postsynaptic outcomes near threshold?”

---

### **Optional: stimulus routing through the auxiliary neuron**

Auxiliary neurons have their own **Stimulus** routing controls:

- **Apply Direct Current Stimulus**
- **Apply Light Stimulus**
- plus the **Photo-Receptor** parameters (Photo-Gain, Decay λ, Recovery λ)

This enables an additional “sensory network” demonstration:

- Use the stimulus generator to drive the **auxiliary neuron** (current or light pathway).
- Route the auxiliary neuron to the main neuron with **Synapse main neuron**.
- The main neuron now responds indirectly to the stimulus via a presynaptic unit.

Teaching translation:
> “A sensory-like input drives one neuron, which then drives another neuron through a synapse.”

---

### **Common pitfalls**

- **No effect on main neuron after enabling coupling**  
  Check:
  - auxiliary neuron is actually spiking (increase Patch Clamp or reduce inhibitory inputs)
  - synapse gain is not near zero
  - you are editing the correct synapse (Synapse 1 vs Synapse 2)

- **Main neuron saturates / spikes continuously**  
  Reduce:
  - auxiliary neuron drive (Patch Clamp)
  - synapse gain (excitatory)
  - noise level

---

### **Links**

- Practical synapse experiments: [Synapses and inputs](../experiments/synapses-and-inputs.md)  
- Two-unit motifs: [Network with two units](../experiments/network-two-units.md)

---

## **Recording in emulator mode**

Emulator mode includes a **Data Recording** box:

1. Set **Data Logging: Filename**
2. Click **Browse directory** to select a save folder
3. Click **Record** to start logging

The output is intended to be analysed exactly like a hardware recording (plot Vm, compute firing rate, build F–I curves, etc.).

See also: **[Recording and export](recording-and-export.md)** and **[Data analysis → Python quickstart](../data-analysis/python-quickstart.md)**.

---

## **Suggested classroom workflow (5–10 minutes)**

1. Start emulator, pick a default neuron mode.
2. Use **Patch clamp** to find threshold (silent → occasional spikes → sustained spiking).
3. Turn on **Noise** and demonstrate stochastic spiking near threshold.
4. Enable **Synapse 1**, make it excitatory, and show how synaptic input can recruit spikes without changing mean injected current.
5. Record 10–20 seconds, export, and plot Vm/spike rate from the CSV.

---

## **What to read next**

- Concepts refresher: **[Concepts](concepts.md)**
- How synapses are used in labs: **[Synapses and inputs](../experiments/synapses-and-inputs.md)**, **[Network with two units](../experiments/network-two-units.md)**
- Imaging link (if you use it): **[Fluorescence imaging simulation](fluorescence-imaging-sim.md)**

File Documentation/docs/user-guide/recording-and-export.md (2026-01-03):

# **Recording and export**

This page explains how to **record data from Spikeling**, how files are saved, what is inside the export, and how to organise recordings for teaching labs.

For a practical walkthrough, see: **[Quickstart → First experiment](../quickstart/first-experiment.md)**.  
For downstream workflows, see: **[Data analysis → Python quickstart](../data-analysis/python-quickstart.md)**.

---

## **What gets recorded (what “data logging” means)**

When you record in the Spikeling GUI, you are saving a time series of the signals you see on screen. Recordings include:

- **Time (ms)** (in 0.1ms increment)
- **Spikeling Vm (mV)** (membrane potential; main trace)
- **Stimulus (%)** (the waveform being applied)
- **Total Current Input (a.u.)** (total input drive; sum of pathways)
- **Synapse 1 Vm (mV)** (Synapse 1 Vm)
- **Synapse 1 Input (a.u.)** (Synapse 1 input current)
- **Synapse 2 Vm (mV)** (Synapse 2 Vm)
- **Synapse 2 Input (a.u.)**  (Synapse 2 input current)
- **Trigger**  (marks the start of each stimulus loop)

!!! note
    The most important teaching feature of Spikeling exports is that **input and output are saved together**. Students can later ask: “What exactly did I apply?” and “How did Vm respond?”

---

## **Where to record from**

### **A) Neuron Interface / Neuron Emulator**
Use this for electrophysiology-style datasets:

- Vm, stimulus, input current, synapse channels, etc.
- ideal for F–I curves, threshold, adaptation, synaptic integration, noise demos

### **B) Imaging Simulation**
Use this when teaching “Vm → calcium → fluorescence”:

- fluorescence and calcium traces can be logged in a separate dataset
- useful for comparing fast Vm signals to slower imaging-like readouts

---

## **How to record (Neuron Interface / Emulator workflow)**

On the **Neuron Interface** (or **Neuron Emulator**) screen, the recording controls are located along the bottom:

1. Click **Browse directory** and choose where recordings will be saved.
2. Enter a **Data Logging: Filename**.
3. Click **Record** to start logging.
4. Click **Record** again (or the stop control, depending on version) to stop logging.

!!! tip "Teaching tip"
    Start recording **2–5 seconds before** your stimulus begins and stop **2–5 seconds after** it ends. Students need baseline segments for interpretation and plots.

---

## **Filename conventions (highly recommended)**

In teaching settings, recordings become confusing quickly unless filenames encode the condition.

A robust convention is:

`YYYY-MM-DD_group_condition_mode_protocol_run.csv`

Examples:
- `2026-01-03_A01_tonicspiking_step20pA_run01.csv`
- `2026-01-03_A01_phasic_noiseNearThresh_run02.csv`
- `2026-01-03_B02_synEplusI_network_run01.csv`

Minimum recommended fields:
- neuron mode
- stimulus type / key parameter
- run number

---

## **What the CSV contains (Spikeling GUI export)**

Spikeling exports one row per sample, with an explicit time column. In the file you provided, the columns are:

| Column (exact header) | Units | Meaning |
|---|---:|---|
| `Time (ms)` | ms | Sample time (in milliseconds). In this export the step is **0.1 ms** (10 kHz sampling). |
| `Spikeling Vm (mV)` | mV | Membrane potential output (Vm). This is the primary signal used for spike detection and interpretation. |
| `Stimulus (%)` | % | The stimulus command level (percentage scale, consistent with the GUI stimulus strength). |
| `Total Current Input (a.u.)` | a.u. | The net input drive delivered to the neuron model (**sum of pathways**), e.g. current injection / stimulus / light / synapses / noise (depending on which are enabled). |
| `Synapse 1 Vm (mV)` | mV | Presynaptic Vm trace arriving via Synapse 1 (from another Spikeling’s axon output). Typically 0 if not connected/used. |
| `Synapse 1 Input (a.u.)` | a.u. | The synaptic current drive produced by Synapse 1 (spike-evoked, exponentially decaying input, scaled by synapse gain). Typically 0 if not used. |
| `Synapse 2 Vm (mV)` | mV | Presynaptic Vm trace arriving via Synapse 2. Typically 0 if not connected/used. |
| `Synapse 2 Input (a.u.)` | a.u. | The synaptic current drive produced by Synapse 2. Typically 0 if not used. |
| `Trigger` | (0/1) | Digital marker for events (protocol timing / stimulus gating / synchronisation). Often 0 most of the time, with pulses during events. |

!!! note
    The `Total Current Input (a.u.)` column is particularly valuable for teaching because it is the best “single summary” of what the neuron is receiving at each moment, alongside the Vm response.

!!! tip "Practical tip"
    If you are exporting for student analysis, encourage them to plot **Vm**, **Stimulus (%)**, and **Total Current Input (a.u.)** together first. That usually resolves most confusion about “what caused what”.

---

## **Exporting from Data Analysis (spike events and averages)**

The **Data Analysis** page provides additional exports that are often useful in teaching:

- **Spike events** extracted from Vm using a chosen threshold  
  (useful for rasters, firing rate plots, and spike-time statistics)
- **Averaged traces** aligned to stimulus cycles  
  (useful when a stimulus repeats and you want a mean response)

Typical workflow:
1. Load a recorded CSV
2. Set spike threshold
3. Display spike events / averages
4. Export as `.csv` and/or save images

!!! warning
    Spike detection depends on threshold choice. In teaching, it is often useful to show that “reasonable thresholds” produce similar spike times, but extreme thresholds can miss spikes or detect false positives.

---

## **Good recording practice (especially in labs)**

### **1) Record baseline**
Always include baseline so students can compare:
- resting Vm vs driven Vm
- spontaneous vs stimulus-evoked spikes
- with/without noise

### **2) Avoid clipping and confusing axes**
If students will analyse the data later, keep plot settings consistent:
- same axis scale across conditions (when comparing)
- avoid autoscale if it hides changes in amplitude

### **3) Keep one change per run**
For clean interpretation, change **one thing at a time**:
- neuron mode *or*
- stimulus strength *or*
- noise amplitude *or*
- synapse gain

### **4) Note the “hardware state”**
If possible, record (in a notebook or spreadsheet):
- mode name
- stimulus type + parameters
- synapse gain sign/magnitude
- photo-gain sign/magnitude
- noise setting

This turns the recording into a reproducible experiment, not just a trace.

---

## **Troubleshooting recording**

### **“Record button does nothing”**
- confirm you selected a valid directory (write permissions)
- check the filename is not empty
- avoid special characters in filenames

### **“File saved but empty / too short”**
- confirm you actually started recording before stopping
- check whether the GUI logs only when the stream is connected/running

### **“Data looks wrong after export”**
- confirm the right traces were enabled before recording
- if time looks compressed or stretched, check whether the export includes timestamps or uses a fixed sampling step
- for multi-unit recordings, confirm synapse channels were enabled

---

## **What to read next**

- How to interpret recorded signals: [Concepts](concepts.md)
- Spike detection and simple metrics: [Data analysis → Spike detection](../data-analysis/spike-detection.md)
- Using Python with exported CSV: [Data analysis → Python quickstart](../data-analysis/python-quickstart.md)

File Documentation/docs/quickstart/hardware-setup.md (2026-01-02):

# **Hardware setup**

This page walks you through the physical setup of Spikeling: powering the board, establishing a USB/serial connection, and preparing the TRS I/O used for analog + digital signals and light stimulation.

## **Identify your board family**

Spikeling exists in two official board families:

- **v2.x (e.g., v2.5)**: ESP32 **WROOM-32**, **mini-USB**, USB-to-UART bridge (**CP210x**)
- **v3.x (e.g., v3.0)**: ESP32 **S3 WROOM-1**, **USB-C**, native USB (**USB CDC serial**), additional DAC IC

If you are unsure, the USB connector is usually the easiest identifier:
- v2.x: **mini-USB**
- v3.x: **USB-C**

## **Step 1 — Connect power and USB**

1. Place the board on a non-conductive surface.
2. Connect the board to your computer using a **data-capable** USB cable:
   - v2.x: mini-USB data cable
   - v3.x: USB-C data cable
3. Avoid charge-only cables. If the board is not detected later, swap the cable first.

!!! tip "Classroom best practice"
    Use a powered USB hub at each station. It improves stability on laptops with weak USB power and reduces intermittent disconnects.

## **Step 2 — Confirm the board appears as a serial device**

This is the most important checkpoint before opening the GUI.

### **v2.x (CP210x) — confirm driver + COM/serial port**

1. Install the CP210x driver if you have not already:
```
https://www.silabs.com/developers/usb-to-uart-bridge-vcp-drivers
```
2. Reconnect the board after installation.
3. Confirm a serial port appears:

**Windows**
- Open **Device Manager**
- Look under **Ports (COM & LPT)** for something like **“Silicon Labs CP210x USB to UART Bridge (COMx)”**

**macOS**
- In Terminal:
  - `ls /dev/tty.*`
- CP210x devices often appear as something like:
  - `/dev/tty.SLAB_USBtoUART`

**Linux**
- In Terminal:
  - `ls /dev/ttyUSB* /dev/ttyACM* 2>/dev/null`
- CP210x commonly enumerates as:
  - `/dev/ttyUSB0`

If no port appears:
- try a different USB cable
- try a powered hub or a different USB port
- confirm the CP210x driver is installed (Windows especially)

### **v3.x (ESP32-S3 native USB) — confirm USB CDC port**

v3.x boards typically enumerate without a separate driver.

**Windows**
- Device Manager → **Ports (COM & LPT)**
- Look for a **USB Serial Device (COMx)** or an Espressif/USB CDC serial entry (naming may vary)

**macOS**
- `ls /dev/tty.*` (or `ls /dev/cu.*`)
- You should see a new `/dev/tty.*` or `/dev/cu.*` entry after plugging the board in

**Linux**
- `ls /dev/ttyACM* /dev/ttyUSB* 2>/dev/null`
- Native USB CDC devices often show up as `/dev/ttyACM0`

If no port appears:
- swap the USB-C cable (most common issue)
- try a different port/hub
- avoid front-panel ports on desktops (they can be noisier/less reliable)

## **Step 2.5 — Choose the right port in the GUI**

When you open the Spikeling GUI, you will need to select the correct serial/COM port.

### **Typical port names (examples)**

**Windows**
- v2.x (CP210x): `COM3`, `COM4`, … (often labeled as CP210x in Device Manager)
- v3.x (USB CDC): `COMx` (often labeled “USB Serial Device” or similar)

**macOS**
- v2.x (CP210x): `/dev/tty.SLAB_USBtoUART` (or similar)  
- v3.x (USB CDC): commonly shows as `/dev/tty.usbmodem*` or `/dev/cu.usbmodem*`

**Linux**
- v2.x (CP210x): `/dev/ttyUSB0` (or another `ttyUSB*`)
- v3.x (USB CDC): `/dev/ttyACM0` (or another `ttyACM*`)

### **If the GUI cannot open the port**

Only one application can own a serial port at a time. If the GUI cannot connect:

- Close **Arduino IDE Serial Monitor**
- Close **PlatformIO Serial Monitor**
- Close any other serial terminal (PuTTY, CoolTerm, screen, minicom, etc.)
- Unplug/replug the board and refresh the port list in the GUI

!!! tip "Fast identification trick"
    Unplug the board, note the list of ports, plug it back in, and select the **new** port that appears.

## **Step 3 — Understand TRS I/O wiring**

Spikeling uses **3.5 mm stereo TRS** jacks to carry both digital and analog signals with a shared ground:

- **Tip (T)** = digital / TTL (trigger, sync, digital events)
- **Ring (R)** = analog signal
- **Sleeve (S)** = ground

### **Recommended cabling practice**

- Use **short TRS cables** for analog signals when possible (reduces noise pickup).
- Keep **sleeve/ground continuity** consistent across connected devices.
- If you need to interface to breadboards or external hardware, use a **TRS-to-breakout adapter** so you can access Tip/Ring/Sleeve explicitly.

!!! warning "Ground matters"
    Many “mystery” issues (noise, unstable readings, incorrect triggers) are grounding problems. If you connect Spikeling to other devices, ensure a shared ground reference via the TRS sleeve or an explicit ground lead.

## **Step 4 — Set up the LED light stimulus (photodiode workflow)**

Spikeling can use a **3.5 mm jack cable wired to an LED** to deliver a light stimulus that the onboard photodiode reads.

1. Plug the LED stimulus cable into the appropriate jack (as used by your board’s light stimulus input).
2. Position the LED so it illuminates the photodiode reliably:
   - keep the LED close and stable (tape or a small mount helps)
   - reduce ambient light if you want clean responses
3. In later steps (GUI), you will use the stimulus controls to drive the LED and observe the photodiode response.

Recommended checks:
- Verify LED polarity and wiring if it does not light.
- If the photodiode response is noisy, reduce ambient light and shorten cables.

## **Step 5 — Quick functional checks (before opening the GUI)**

- [ ] Board is connected with a **data-capable** USB cable
- [ ] A new serial/COM port appears (v2.x: CP210x; v3.x: USB CDC)
- [ ] I can identify the correct port and it is not in use by another program
- [ ] I have at least one **TRS cable** available for I/O
- [ ] (Optional) LED stimulus cable is connected and positioned for photodiode reading

## **Next steps**

- Install and launch the GUI: **[Install the GUI](install-gui.md)**
- Run your first test protocol: **[First experiment](first-experiment.md)**
- If anything fails: **[Troubleshooting](troubleshooting.md)**

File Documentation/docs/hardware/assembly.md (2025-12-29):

# Assembly

Step-by-step assembly instructions with photos and checkpoints.

## Tools

TODO

## Soldering order

TODO

## Inspection and bring-up

TODO

## Common assembly mistakes

TODO

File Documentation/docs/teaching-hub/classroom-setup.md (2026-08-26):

# Prepare a class

Use this page to move from a selected curriculum module to a teachable session. The catalogue specifies audience, duration, group size, boards, equipment, software and dataset needs; it does not replace a local pilot.

!!! warning "Pilot before teaching"
    Nominal timings and activities in the curriculum catalogue are architectural specifications. Validate the complete activity on the target hardware, firmware and GUI versions before using it with students.

## 1. Select the learning route

- For a first encounter, start with [FND-01 — First contact](modules/foundations.md#fnd-01) and the operational [first experiment](../quickstart/first-experiment.md).
- For a practical class, choose from the [current practical guides](teaching-resources.md#current-practical-guides).
- For a workshop or course, use the [dependency pathways and course bundles](course-module-outlines.md).
- For an unreleased catalogue module, follow the [full module-development template](development-status.md#template-for-later-full-module-development) before treating it as a handout.

## 2. Validate each teaching station

Complete these steps on every computer and board combination that students will use:

1. Check [what you need](../quickstart/what-you-need.md).
2. Complete the [hardware setup](../quickstart/hardware-setup.md).
3. [Install and open the GUI](../quickstart/install-gui.md).
4. Run the [first experiment](../quickstart/first-experiment.md).
5. Confirm that recording and export work using the [recording guide](../user-guide/recording-and-export.md).
6. Record the board, firmware and GUI versions used for the pilot.

## 3. Apply the validation gates

Complete [EPH-04 — Sampling and timebase validation](modules/electrophysiology.md#eph-04) before interpreting latency, firing rate, interspike intervals, spectra, phase or kinetic constants.

Imaging-indicator comparisons and extracellular timing/spectral activities require the additional parameter and timestamp checks described in [Development status and validation gates](development-status.md#recommended-development-order-and-validation-gates).

## 4. Prepare the teaching package

For a release-ready module, prepare the elements required by the curriculum architecture:

- version and empirical-validation record;
- instructor preparation and pilot checks;
- student activity and observable outcomes;
- variable, unit, sample-interval and metadata specification;
- analysis notebook or a tested non-code alternative where required;
- evidence-based questions and artefact criteria;
- accessibility and differentiation variants;
- explicit interpretive limits; and
- a fallback dataset when the activity depends on acquisition.

The live documentation does not yet ship validated fallback datasets or teaching notebooks. Do not assume that a catalogue reference to prepared data means the file is already available.

## 5. Plan support during the session

Keep the [quickstart troubleshooting guide](../quickstart/troubleshooting.md) available to instructors and teaching assistants. For multi-station triage and escalation routes, see [Troubleshooting at scale](troubleshooting-at-scale.md).

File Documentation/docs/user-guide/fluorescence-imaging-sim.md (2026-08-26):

# **Fluorescence imaging simulation**

This page explains the **fluorescence imaging simulation** in the Spikeling GUI: what it represents, how it is computed from membrane potential (**Vm**), and how to use it for teaching.

Spikeling’s imaging simulation is not a camera and not a microscope pipeline. It is a **conceptual bridge** between:
- fast electrical activity (Vm and spikes), and
- slower optical readouts (calcium and fluorescence) that students commonly see in modern systems neuroscience.

See also:
- [Concepts](concepts.md) (why Vm can be transformed into fluorescence)
- [GUI overview](gui-overview.md) (where the Imaging screen lives)
- [Teaching Hub → Imaging module specification](../teaching-hub/lab-handouts/lab-04-imaging.md)

---

## **What this simulation is **

- a teaching model that converts **Vm / spiking activity** into:
  1) a simulated **intracellular calcium** trace, and  
  2) a simulated **fluorescence** trace
- a way to explain why fluorescence signals are:
  - delayed relative to spikes
  - smoother (low-pass filtered)
  - often non-linear and baseline-dependent
- a tool for demonstrating common analysis concepts such as **ΔF/F**

---

## **The conceptual pipeline: Vm → calcium → fluorescence**

The simulation is built around three simple ideas that match how students should reason about imaging data:

### **1) Spikes drive calcium influx**
Spikes (or spike-like events inferred from Vm) are treated as the main driver of calcium entry.

Teaching translation:
> “A spike happens quickly, but calcium rises and decays more slowly.”

### **2) Calcium is slow compared to Vm**
The calcium trace is a **filtered** representation of spiking: it rises with activity and decays with a characteristic time constant.

Teaching translation:
> “Even if Vm returns to baseline, calcium can stay elevated.”

### **3) Fluorescence is a transformation of calcium**
The fluorescence trace is a further transformation of calcium into an optical-like signal. In real imaging, this relationship can be non-linear and depends on indicator kinetics and baseline.

Teaching translation:
> “Fluorescence is an indirect proxy for spikes, not a direct measurement of Vm.”

---

## **Where to find it in the GUI**

Go to:

**Imaging → Imaging Simulation**

The imaging screen is designed to look and behave like the main oscilloscope page, but for calcium/fluorescence.

---

## **How to use the Imaging Simulation screen**

### **Step 1 — Choose a source**

Spikeling imaging can be driven by either:

- **Spikeling hardware** (live Vm stream from the device), or
- **GUI emulator** (no hardware required; best for demonstrations)

Use the “source” selector (e.g., *from GUI emulator*). If you are teaching a class without enough devices, the emulator is often the cleanest option.

### **Step 2 — Choose which traces to display**

Typical display options include:

- **Vm** (Spikeling and optional Synapse channels)
- **Calcium** (Spikeling and optional Synapse channels)
- **Fluorescence** (Spikeling and optional Synapse channels)
- **Stimulus** (so students can align cause and effect)

### **Step 3 — (Optional) Enable ΔF/F**

ΔF/F is a common normalised fluorescence metric.

- **F** is a baseline fluorescence level (often estimated from a low-activity period)
- **ΔF** is the change relative to baseline
- ΔF/F makes it easier to compare recordings with different baseline brightness

Teaching translation:
> “ΔF/F is a normalised measure of relative activity rather than absolute brightness.”

### **Step 4 — Axis scaling**

If available, **Auto Range Y axis** is helpful in early demos.
For comparative labs (same stimulus, different mode), it is often better to keep axis ranges fixed so students can compare amplitudes honestly.

### **Step 5 — Record imaging data**

The imaging screen includes a recording section similar to the Neuron Interface:

1. Choose a **directory**
2. Enter a **filename**
3. Press **Record**

This produces an export students can analyse later (e.g., comparing Vm vs fluorescence timing).

---

## **What students should learn from it**

### **Key lesson 1: fluorescence is delayed**
A spike occurs in milliseconds. Calcium and fluorescence typically peak later. Students should be able to answer:
- “Why does fluorescence peak after spikes?”
- “Why can fluorescence remain elevated after spiking stops?”

### **Key lesson 2: fluorescence is smoother**
Vm can contain sharp spikes and fast oscillations. Fluorescence is slower and smoother. Students should be able to explain:
- why fast voltage features are lost in fluorescence
- why individual spikes can merge into a single broad transient at high firing rates

### **Key lesson 3: the mapping is not one-to-one**
At low firing rates, individual spikes may produce distinct transients.
At higher rates, transients overlap and it becomes difficult to infer exact spike timing.

This supports a core modern neuroscience idea:
> Imaging is excellent for population activity patterns, but it is not a direct substitute for electrophysiology when precise spike timing is required.

---

## **Suggested demonstrations (work well in teaching)**

### **Demo A — one stimulus, two neuron modes**
1. Keep the stimulus the same (e.g., square-wave or a step protocol).
2. Switch neuron mode (tonic spiking vs adapting / phasic).
3. Observe:
   - Vm spikes differ strongly across modes
   - calcium/fluorescence patterns differ (peak height, decay, steady-state)

Teaching question:
> “Does fluorescence reflect ‘number of spikes’, ‘burstiness’, or both?”

### **Demo B — frequency sweep (chirp / ZAP-like input)**
1. Apply a chirp stimulus (linear or exponential sweep).
2. Observe Vm resonance-like behaviours (if present) and how fluorescence averages over them.

Teaching question:
> “Which features survive the Vm → fluorescence transformation?”

### **Demo C — near-threshold noise**
1. Hold Vm just below threshold (DC injection / patch clamp).
2. Add noise until occasional spikes occur.
3. Observe that fluorescence becomes an intermittent transient signal.

Teaching question:
> “Why is imaging often analysed statistically rather than spike-by-spike?”

---

## **Common pitfalls and how to explain them**

### **“Fluorescence does not look like Vm”**
Correct: it should not. Fluorescence is downstream of calcium kinetics and indicator dynamics.

### **“My fluorescence amplitude changed when I changed baseline”**
That is expected. Baseline and normalisation (ΔF/F) matter a lot in optical measurements.

### **“I cannot infer exact spike timing from fluorescence”**
Also expected, especially at high firing rates where transients overlap.

---

## **What to read next**

- How to record and export: [Recording and export](recording-and-export.md)
- Analysis of fluorescence-like signals: [Data analysis → Fluorescence analysis](../data-analysis/fluorescence-analysis.md)
- Curriculum specification: [Teaching Hub → Imaging module](../teaching-hub/lab-handouts/lab-04-imaging.md)

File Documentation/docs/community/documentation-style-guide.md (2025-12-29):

# Documentation style guide

House style for consistent, maintainable documentation.

## Page template

TODO

## Voice and tone

TODO

## Screenshots and figures

TODO

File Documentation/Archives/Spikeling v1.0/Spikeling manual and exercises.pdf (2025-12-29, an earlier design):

# Spikeling User Manual

## Content

Version 1. 6

th Sept 2018.

## Assembly From Parts

If desired, all parts can be conveniently sourced through Kitspace: https://kitspace.org/boards/github.com/badenlab/spikeling/

When using this option, please be aware:

1) Kitspace will almost certainly not find the cheapest Arduino Nano (clone). You should be able to get one for less than £3. Similarly, PCB manufacturing options suggested may also not be the cheapest. Google is your friend here!
2) Kitspace will likely find some options where “packs” of components are listed (e.g. instead of the 2 optional screws to hold the optional battery pack in place, it may find a box of 100). So, when using the option, do carefully go through the suggested purchase list and edit as appropriate.
3) Obviously, when buying in bulk, things can get a lot cheaper (potentially several-fold savings per unit).

Solder all parts in place as per the below. An introduction to soldering is here: https://www.howtogeek.com/63630/how-to-use-a-soldering-iron-a-beginners-guide//.

For details on parts, see Bill of materials (BOM).

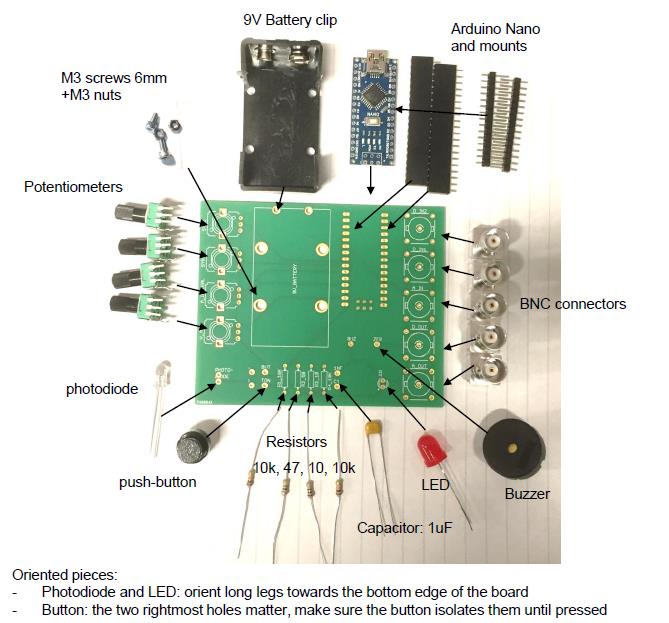
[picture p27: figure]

When complete, it should hopefully look like this:

Note: If it doesn’t seem to work, 9 out of 10 times it’s because 1 of the following:

1) Did you upload the Arduino script? If not sure how to do that, see below under getting started.
2) Somewhere, 2 or more contacts that shouldn’t touch, so in fact touch and thus short-circuit something. Carefully check the board (both sides, solder can leak through the holes and make unwanted contacts on the other side). To check, it can be instructive to “beep” the circuit with a multimeter (google that if unsure). If you have a short circuit, remove it. Usually, simply reheating the pad may do the trick, but if not, used a solder sucker.
3) “Cold contacts”, i.e. an intended contact that are not actually connected. This can easily happen e.g. if the parts are slightly moved during soldering, such that in the last second, as the solder hardens, the pieces come apart. They may then “look” like they are fine, but don’t conduct. Check with multimeter, or simply re-heat all the dodgy looking contacts.
4) Did you solder the oriented pieces the right way round? (see previous page)

You will know if it works if you power it (Battery or USB cable), with all dials turned to midpoint, if you then crank up dial 4 or hold it into the light, it should start to spike (audible clicks coupled to flashes from the LED). Congratulations, you have successfully built a Spikeling!

## Getting Started

Turn all dials to midpoint (you should feel a gentle “click”) and power the board (via USB, or via 9V Battery). The Arduino LEDs should come on. If the board is already on, press the small white reset button on the Arduino itself (not the big black button on the board). This will take a few seconds and puts Spikeling in “reset state” (i.e. mode 1, with all dials to midpoint). All instructions below assume you start from here.

The reset state mimics the “average textbook neuron” - a vertebrate spiking neuron with a resting membrane potential around -70 mV and a spike threshold around -55 mV.

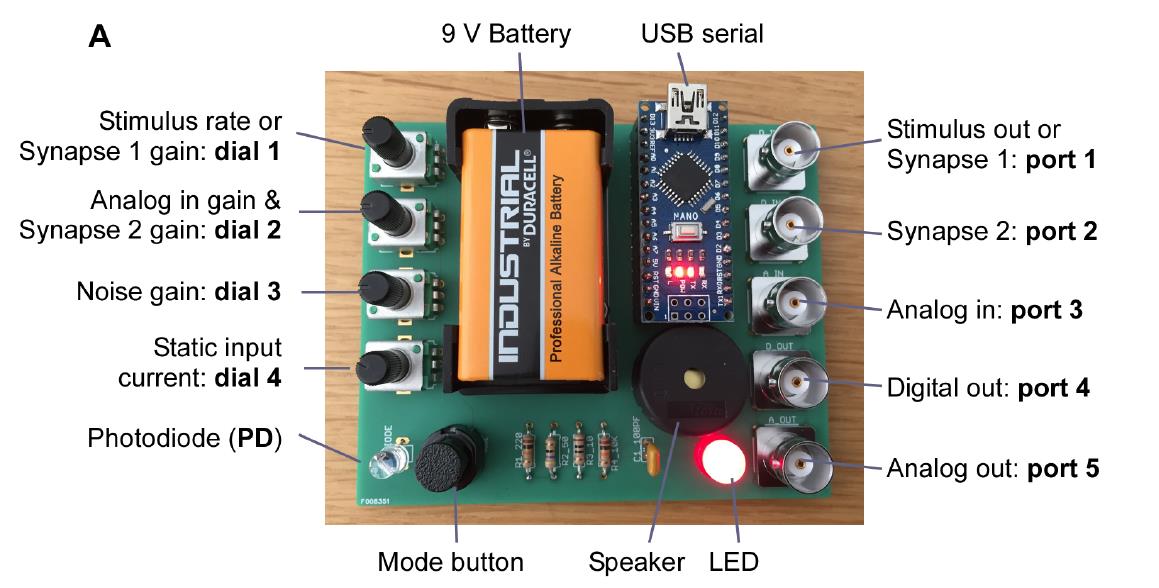
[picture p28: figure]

To visualise and record the activity of Spikeling, there are several options but the best is via a serial connection to a PC through the USB connection on the Arduino. Here we describe how to use the Serial-Oscilloscope software package provided (under creative commons from http://x-io.co.uk/serial-oscilloscope/). This lets you read all output parameters directly from the Spikeling board for display on the screen or for logging. There is also a YouTube video (https://www.youtube.com/watch?v=jgMG0UQ2_pc) demonstrating how to set up the oscilloscope.

1) Make sure the Arduino IDE is installed as you need the driver (www.Arduino.cc). Note that if you are using an Arduino-clone, the standard drivers may not work. In this case, google for the correct ones and install those instead.
2) Declare the serial port. When you plug the USB cable into the PC you may see a message telling you which “COM-port” is being used. This is the “serial port” which you need to set in the menu of the serial oscilloscope. It may just give one option which is then probably the correct one. The COM port is also found under the Device manager.
3) Set the Baud Rate to 230400.
4) The window should now produce a continuous stream of numbers. These are the output values from Spikeling. To plot them, open the oscilloscope(s) under the menu. Spikeling outputs 9 parameters in parallel, but each oscilloscope window can only display 3. If you need parameters further down the list, simply open a second oscilloscope. You can separately adjust the scale of each trace on the oscilloscope by first selecting it (click the “Beam” button) and then scaling it (left-most thin arrows) and off-setting it (big red arrows). You can also trigger the oscilloscope using the menu on the bottom right.
5) To record data, click “log to file”. This will write a text file (comma and tab separated ASCII) with all numbers output from Spikeling. You can look at this output using any common data-analysis software (for example GNU-R, which is free, or Igor Pro or MATLAB, which are licensed).

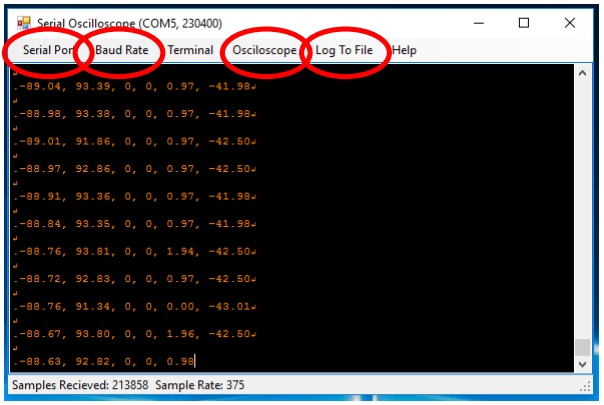
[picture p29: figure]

The output parameters of Spikeling are as follows:

1) Membrane voltage Vm (in “mV“)
2) Total input current Itotal (in arbitrary units). Itotal = IVm + IPD + ISyn1 + ISyn2+ IanalogIn
3) Stimulus state of Synapse 1 port (see below, range 0-1)
4) Synapse 1 state (see below, boolean 0-1 for nospike / spike in the input)
5) Synapse 2 state (see below, boolean 0-1 for nospike / spike in the input)
6) Total photodiode current IPD (in arbitrary units)
7) Total Analog In current IanalogIn (in arbitrary units)
8) Total Synaptic current ISyn (in arbitrary units) ISyn = ISyn1 + ISyn2
9) System time since last reset (in microseconds)

You can also read Spikeling’s Vm output via the BNC ports using a regular oscilloscope. Digital Out only carries the spikes (TTL 5V) while Analog Out on port 5 carries a version of the analog membrane voltage (in arbitrary units). (Note that this output is a pulse-width modulated (PWM) digital signal that is RC-filtered to produce and analog out: it will therefore display filtering artefacts).

Note: If Spikeling is doing “weird things” that clearly does not align with this manual, chances are there is a bad solder contact somewhere – either connecting two pins that should not be connected, or not connecting pins that should be connected (e.g. due to cold solder contacts). Check all contacts carefully and redo them if necessary (i.e. heat them up briefly so they can resettle). It can be worthwhile checking connections with a Multimeter, if available.

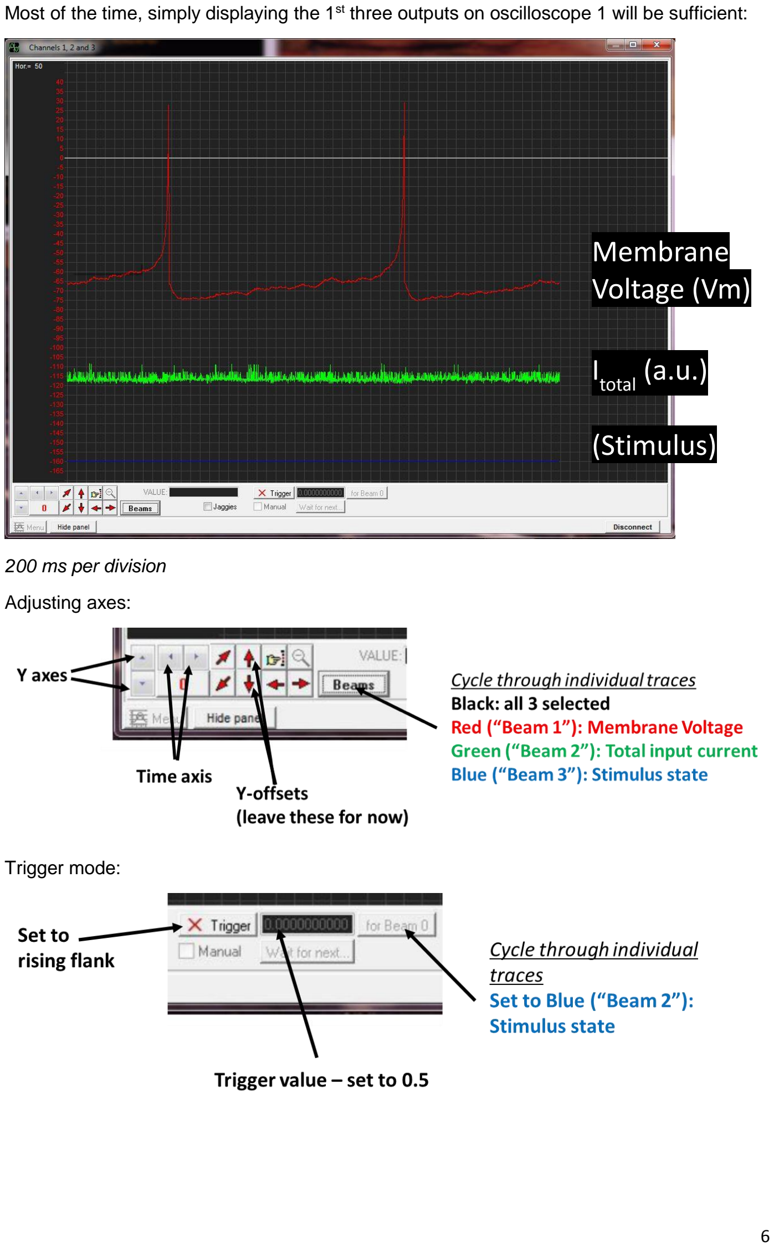
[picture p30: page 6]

Most of the time, simply displaying the 1st three outputs on oscilloscope 1 will be sufficient:

200 ms per division

Adjusting axes:

Trigger mode:

# Membrane Voltage (Vm)

I

# total (a.u.)

# (Stimulus)

## Visualising Spikeling Output with MATLAB

The Serial Oscilloscope plotter saves recordings in comma-separated CSV files. These can be read by a wide range of software: open source possibilities include GNU-R (https://www.r-
project.org), | Python | (https://www.python.org) | or | Octave
(https://www.gnu.org/software/octave/). To comply with software preinstalled on the teaching PCs available at the University of Sussex, we chose to use MATLAB (Mathworks). MATLAB licenses are, however, costly and below we also provide instructions on the use of Python (free!) for visualising Spikeling output.

After opening MATLAB, make sure you have the recorded data and the MATLAB scripts in the same folder. Navigate to that folder (alternatively, the scripts/data may be added to the path.)

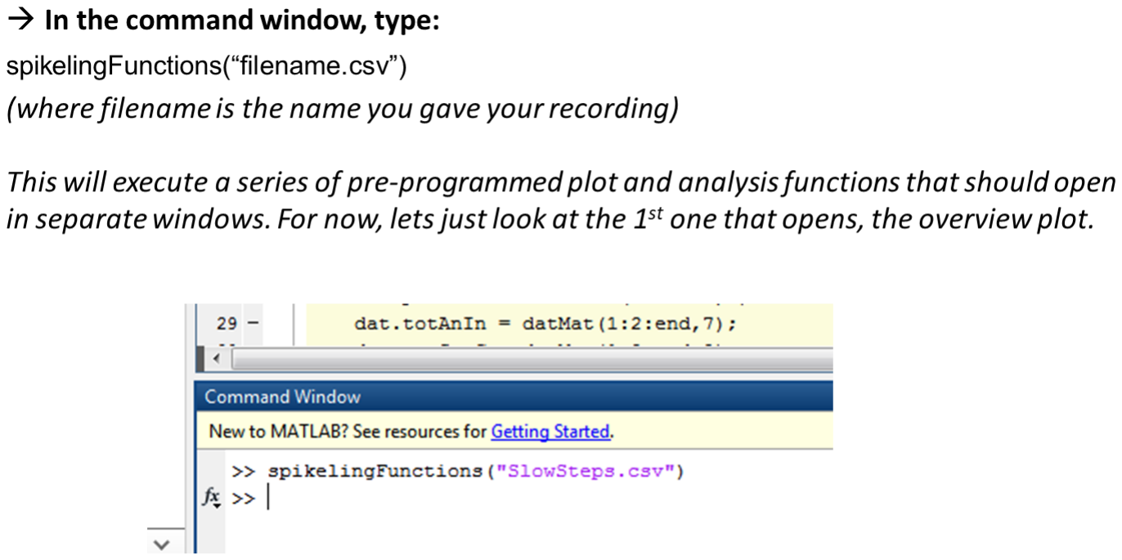
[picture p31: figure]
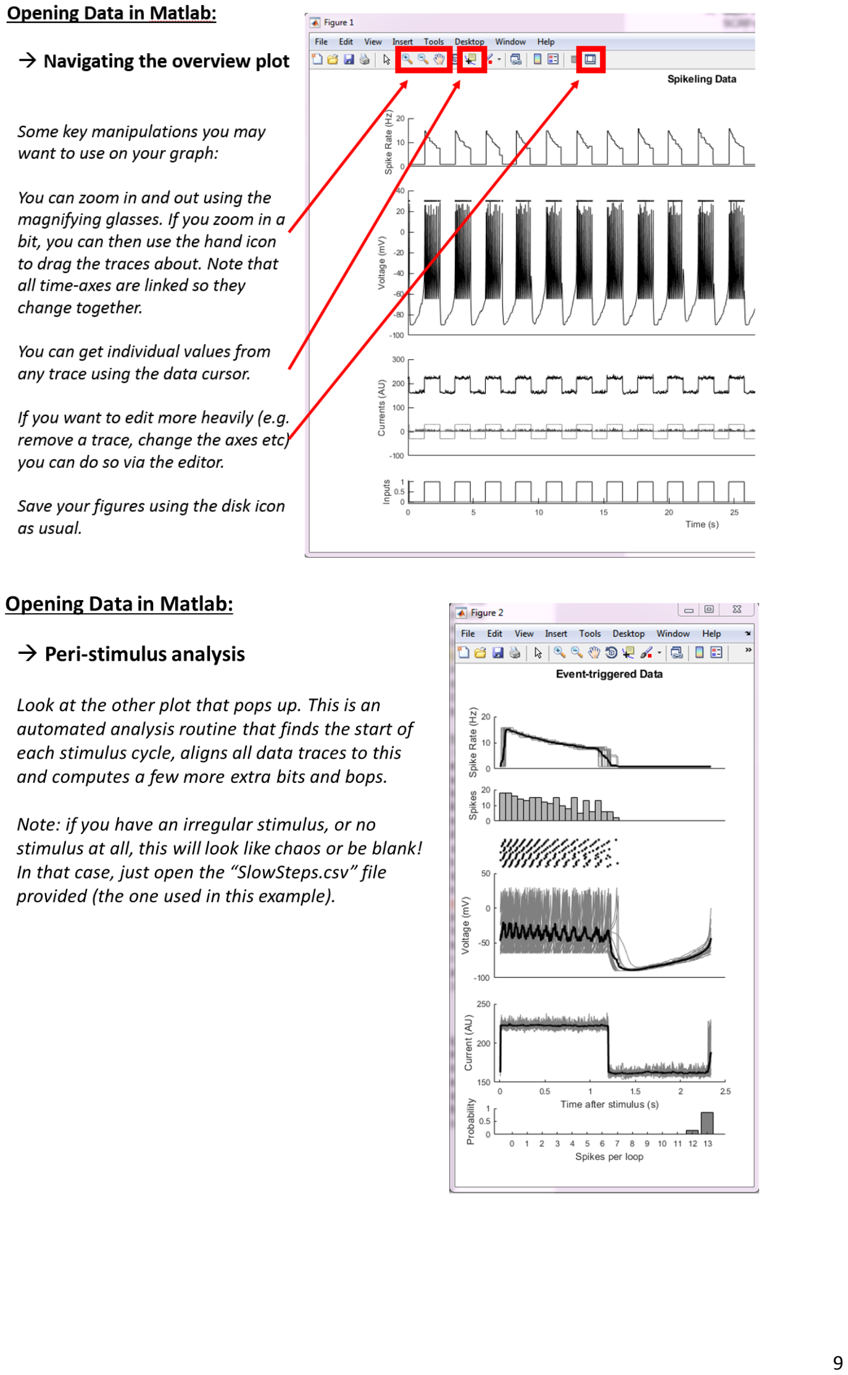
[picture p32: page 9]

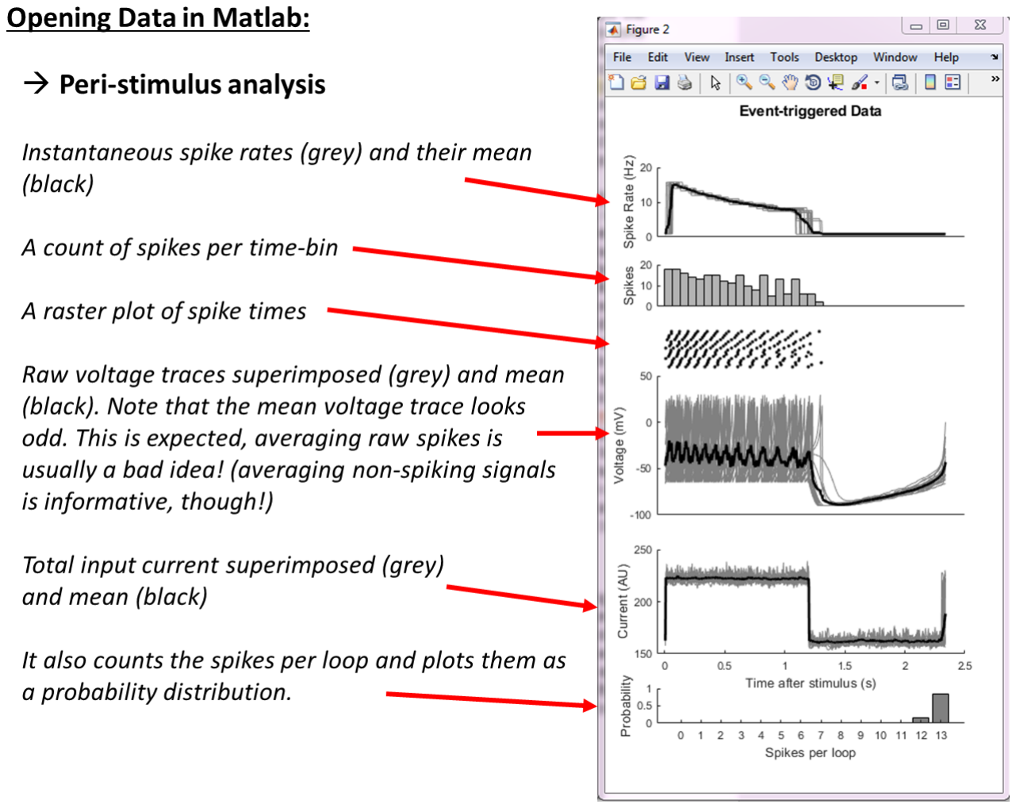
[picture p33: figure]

## Visualising Spikeling Output with Python

We also provide similar scripts in Python (which is free) in the form of a Jupyter Notebook (http://jupyter.org) that reads the serial plotter’s logged csv file, detects spikes, aligns the data in different ways and plots the results in simple graphs. Here we provide a brief explanation of how to run the Python code, rather than a repeat of the detailed explanation of the plot functions.

### Getting started with Python

While the Jupyter Notebook could principally also be executed directly from GitHub without installing Python, this would quickly generate issues with the way that the script provided loads the csv data. For simplicity and convenience, we therefore here give a brief account of how to execute and modify the script in Anaconda.

1) Download Anaconda (it’s free). Navigate to https://conda.io/docs/user-guide/install/, pick the right version for your operating system and follow the install instructions given
2) Once installed, launch a Jupyter Notebook, for example by executing the Anaconda Navigator and clicking “launch” under the corresponding tab. This will open a window in your web browser showing some folders on your home hard drive. Here, navigate to the folder containing the Jupyter script provided (Spikeling Analysis.ipynb) and open that script.

3) Also copy whatever csv file recorded with Spikeling you want to analyse. In the example given below, this will be the file SlowSteps1.csv in the zipped Example Data provided.
4) Your screen should now hopefully look something like this:

### Using the Juypter Notebook

Jupyter notebooks are organised into “cells” (each grey area) which can be called individually. Alternatively, all cells can be called at once (in sequence) to execute the whole thing.

Before doing so, make sure that the file name to be analysed is entered where it says:

data = np.loadtxt(‘SlowSteps1.csv’, delimiter = ‘,’)

i.e. if you wanted to read a file name “SomeNewData27.csv” that line should read:

data = np.loadtxt(‘SomeNewData27.csv’, delimiter = ‘,’)

Now, click on the topmost cell (i.e. where it reads “Load raw data”) and then click “run”. This will execute that one cell and jump to the next (which in this case it doesn’t do anything interesting). If you now keep clicking “run”, it will execute each cell of the script in sequence.

To run the whole thing in sequence (not ideal as the bottom of the script has some optional bits) you can also press the >> button 3 steps to the right of “Run”

Once you reach the first plot, it should open up a new tab that simply plots the raw data (and detected spike times). It should hopefully look something like this:

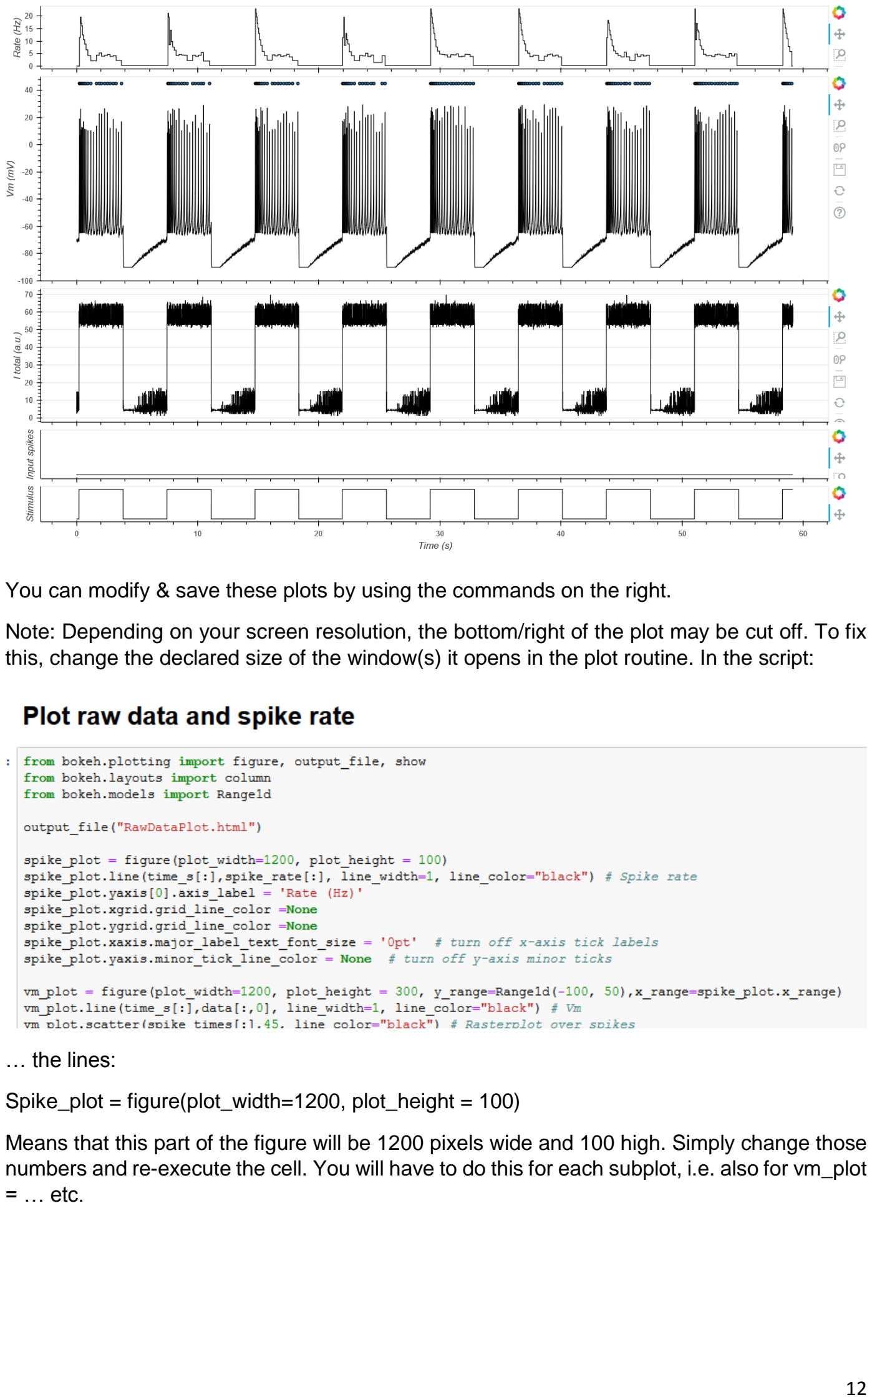
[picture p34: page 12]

You can modify & save these plots by using the commands on the right.

Note: Depending on your screen resolution, the bottom/right of the plot may be cut off. To fix this, change the declared size of the window(s) it opens in the plot routine. In the script:

… the lines:

Spike_plot = figure(plot_width=1200, plot_height = 100)

Means that this part of the figure will be 1200 pixels wide and 100 high. Simply change those numbers and re-execute the cell. You will have to do this for each subplot, i.e. also for vm_plot = … etc.

### Plotting Stimulus aligned data

Following execution of the subsequent the “Analysis Open 1…” cells, a few cells further down, under heading “plot stimulus aligned data” it will generate the stimulus aligned plot. The dimensions of this can be altered in the same way as described above, if required.

### Plotting STAs

Alternatively, if the data is a “noise sequence” generated to recover linear filters (spike triggered averages, STA), skip the whole part that says “Analysis Option 1…” and go straight to “Analysis Option 2: Spike triggered average (STA)”.. Executing this cell will give the STA:

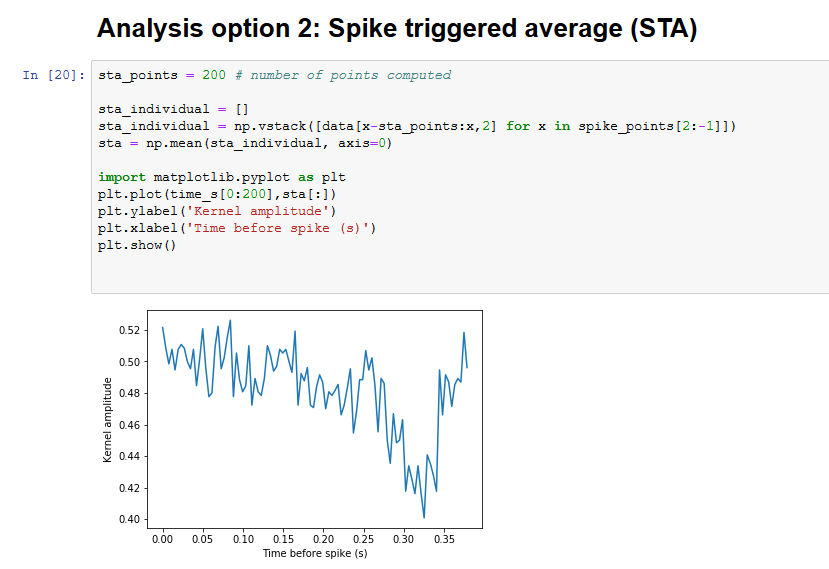
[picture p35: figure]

(here shows the result for the STA of the example data “Noise_Mode3.csv”)

## Reprogramming Spikeling (Arduino)

The “brain” of Spikeling is the Arduino-Nano microcontroller (the blue thing). By tweaking the code that is uploaded here (via the USB cable from the Arduino IDE) it is fairly straightforward to modify Spikeling behaviours, for example by modifying some of the “mode settings”. When opening the Arduino code, in the top there is a list of variables and arrays with some annotations. These should be the 1st point of contact when modifying the code. After each modification, the code needs to be saved and uploaded to the Arduino for the change to take effect.

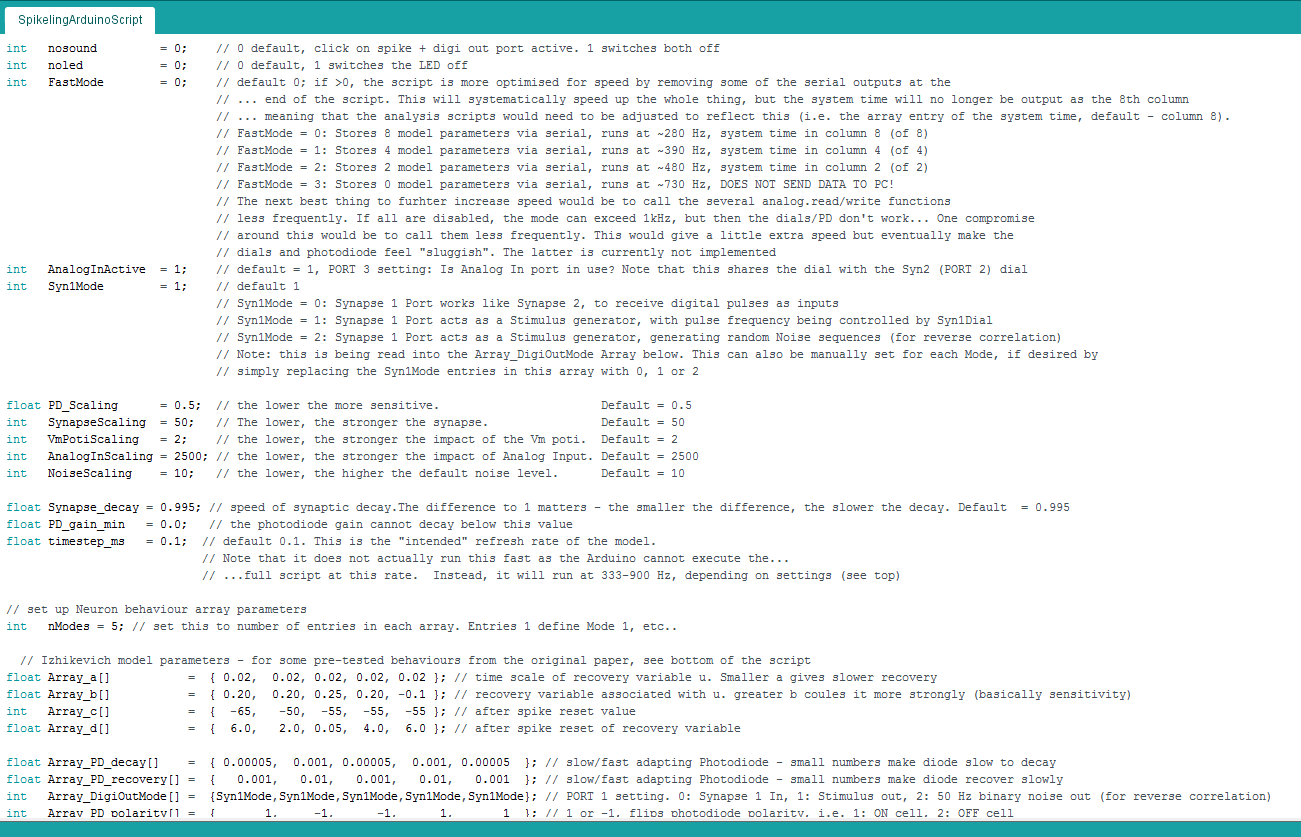
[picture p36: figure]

The screenshot above shows the main variables to tune if desired. For example, replacing the nosound variable currently set to “0” with a “1” will stop the clicking whenever it spikes (note it will also disable the Digi out port as these are on the same connector!).

To modify an existing “mode”, you need to edit the corresponding entries in the 8 arrays listed below “Izhikevich model parameters”. For example, switching the first entry in Array_PD_polarity from currently “1” to “-1” will invert mode 1’s photo-response to make it an “Off-cell”. In the same way, changing the “1” to a “2” will double the gain of the photo-response, etc.

To add new modes, or delete existing ones, simply set the nModes parameter to the new number of entries in each array (must be the same!) and modify the arrays accordingly. For a handy lookup of useful Izhikevich model parameters, scroll to the bottom of the code.

Note: Due to space constraints on the PCB, two Spikeling ports/dials are double booked by two functions. These are:

i) Synapse 1 & Stimulus out use the same port (1), and cannot operate at the same time. This is defined in the Array_DigiOutMode array. “0” enables Synapse 1, “1” enables the 50% duty cycle pulses digi out (default) and “2” enables the 50 Hz noise stimulus used for estimating linear filters (cf. Fig. 6).

ii) Analog In and Synapse 2 gain use the same dial (2). Usually this does not create a conflict as in most cases either Analog In and synapse 2 are not used at the same time. If a conflict arises, it is possible to switch off the Analog In gain using the AnalogInActive variable (set to 0). Advanced users may also choose to re-port these functions in the core code – this would involve resetting the port variables in “void setup” and checking that any use of these ports in the remainder of the code aligns with that change.

### Arduino Implementation of Izhikevich Model

The Izhikevich model is implemented by iteratively computing voltage (v) based on two equations:

(1) v = v + timestep_ms * (0.04 * v * v + 5*v + 140 – u + I_total);
(2) u = u + timestep_ms * (Array_a[NeuronBehaviour] * (Array_b[NeuronBehaviour]*5 – u));

and two conditionals:

(3) if (v>=30.0) {v=Array_c[NeuronBehaviour]; u+=Array_d[NeuronBehaviour];}
(4) if (v>=-90) {v=-90.0);}

In detail:

Lines (1) and (2) are the main model implementations, where…

…we first compute the new value for voltage (v) by adding a quadratic formula of v with recovery variable (u) subtracted, followed by the addition of a single number I_total that reflects the summed input currents (from static input current, photodiode, analog in, synaptic currents etc.)

… and then we re-compute a new value of the recovery variable (u) based on Array entries Array_a and Array_b at position NeuronBehaviour (=the mode, switchable by the onboard button). At default, NeuronBehaviour == 0, so the 1st entries in Array_a and Array_b are used, and when pressing the button NeuronBehaviour is incremented by +1 each time until it resets if it exceeds nModes (further up in the script). The Arrays are found near the top of the script, and reflect the original parameters a, b (& c, d, see below) from the model. Generally, a larger value of u hyperpolarises the model in the next computation of u, as it directly opposes I_total.

In both lines (1) and (2), the increment to v and u is scaled by global variable timestep_ms (default = 0.1). This reflects the “intended” model refresh rate. So, if that set of equations were called 10 times per millisecond (i.e. at 10 kHz) the model would run at “real-time”. However, the actual call-rate is much lower, as the Arduino cannot execute the full script at 10 kHz. In standard configuration, it actually runs at only ~420 Hz. Ways to increase speed are discussed below (“Spikeling Refresh Rate”).

Next, lines (3) and (4) are two conditionals that are triggered as a spike occurs (3) or if membrane voltage drops too low (4).

Line (3) is a carbon copy version of the original Izhikevich model, where upon execution of a spike (v exceeding 30 mV) the model resets the new value of v to be equal to Array_c[NeuronBehaviour] and resets the value of u according to Array_d[NeuronBehaviour].

Line (4) is a custom addition to the model that stops it from hyperpolarising below -90 mV. This is non-essential, but stops the model from crashing if, for instance,I_total becomes too negative to drive unrealistically low membrane voltages.

The functions of Array entries a, b, c and d are explained in detail in the original paper (Izhikevich 2003). The paper and later online additions also give a list of possible “useful combinations” of a, b, c and d that together give the model different “realistic” behaviours. For convenience they are also pasted into the bottom of the Arduino script. To implement them, simply take a specific behaviour’s 1st 4 numbers and add them to the four arrays in the top of the script:

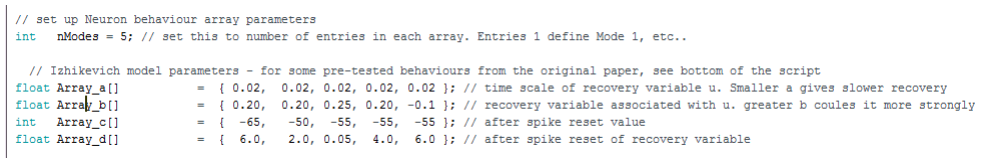
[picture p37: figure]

### Photodiode Adaptation Speed

The photodiode is inherently noisy, so here we use a “buffered time-averaging” of its signal to ameliorate some of the noise. Instead of just reading it’s state on the corresponding AnalogIn Pin (1st line, PDVal) and sending that drive directly into the model as I_PD, we instead send each instance of PDVal into a buffer array PDVal_Array of size 10. Each time the buffer is full (after 10 instances of PDVal being stored in the buffer), we take its mean (PDVal_smoothed) and use that number to inform I_PD.

Next, the Photodiode also has two gain factors (global scaling, and local gain) and two decay constants (time dependent) associated, which allows to have the PD current adapt over time, as it would in most sensory neurons.

- PD_Scaling is global and set at the beginning of the script. This is a single number that scales the amplitude of all PD_related amplitude processes
- PD_gain is the current gain of the PD system. At default, this is 1, but it falls below 1 if the PD in continuously driven, and recovers thereafter as a function of the time-dependent variables, both of which are stored in Arrays at the top of the script and depend on the Mode variable NeuronBehaviour:
- Array_PD_decay[NeuronBehaviour]
- Array_PD_recovery[NeuronBehaviour]
- PD_gain is limited at the top at 1 (full gain), and and the bottom at PD_min (default = 0, which will also have I_PD at 0).
- Finally, as I_PD is being used in the Izhikevich model (see previous section) it is multiplied by either 1 (no change) or -1 (invert), to allow flipping its polarity as a whole thus mimicking “On” and “Off” type behaviour, respectively. This flip is controlled by a third array: Array_PD_Polarity[NeuronBehaviour]

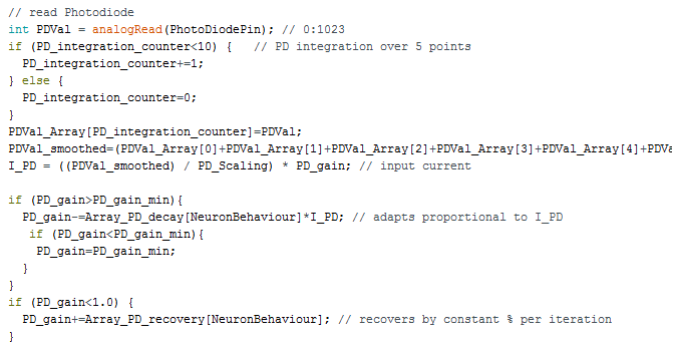
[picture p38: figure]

Photodiode-related arrays at the top of the script:

### Model Noise

Spikeling allows adding synthetic noise to the model, to mimic noisiness in neurons. The noise is added to the I_total variable read in the Izhikevich model as I_Noise. The dial (3) controls the amplitude of the noise around 0 (NoiseAmpl), but has no impact on it’s temporal statistics. This noise function was added in a fairly simple way: At each model instance a single variable I_Noise is increased/decreased by a random amount as a function of NoiseAmpl, followed by a “dampening” step of multiplying the result by 0.9. The dampening step is used to ensure the Noise parameter slowly tends towards 0, as otherwise random noise fluctuations would accumulate to drive sustained de- or hyperpolarising current. Accordingly, the temporal statistics of the noise depend on model refresh rate (see corresponding paragraph below) and this arbitrary dampening factor. We found that a value of 0.9 produces “realistic-looking” noise.

### Spikeling Refresh Rate

The Izhikevich model works by iteratively computing v and u as a function of each other and model parameters a, b, c and d (see corresponding paragraph above). Each time this set of equations is called, the model advances by one unit of time. Accordingly, the more frequently the main loop of Spikeling can execute (“void loop”), the faster the model can run. However, this main loop includes several pieces of code that execute “slowly” (100s of microseconds), limiting the refresh rate. In “standard configuration” (i.e. all parameters set as described in the paper and as provided in the Arduino sketch), the model executes at 420 Hz as 1 full execution round of the void loop takes ~2.4 ms. This leads to a potential conflict: if the Izhikevich timestep parameter (timestep_ms, see above) were set to 2.4 ms to try to achieve maximum speed of the model, it would in fact fail because the model is set-up to mimic fast action potential generation in the mammalian central nervous system where a single spike typically lasts 1 ms at most.

Instead, to get realistic (if slowed down) waveforms of action potentials and subthreshold events, the model should be executed at an intended model rate of ~10 KHz (i.e timestep_ms = 0.1, the default value). Although the model will be executed in 0.1 ms instances, these instances are only called every 2.4 ms so that the model runs ~24 times slower than intended. The waveforms of spikes and subthreshold events continue to look realistic to the observer, they are simply a bit slow. One way to think of this might be to consider Spikeling output as mimicking neurons of cold-blooded animals, where these types of kinetics are commonplace.

### Speeding up the model

If desired, the user can speed up the execution of the model in several ways. Simply put, there are 2 main factors slowing down the loops: Serial Print operations and Analog Read/Write operations. Accordingly, reducing the number of these operations, or the frequency at which they are called will speed up the model.

Serial Print operations are used at the end of the script to log model data via the USB connection to the computer. At default, it logs 9 parameters, in this order:

- Voltage v
- Total current I_Total

- Model Stimulus State Stim_State
- Synapse 1 State (spikes in?) SpikeIn1State
- Synapse 2 State (spikes in?) SpikeIn2State
- Photodiode current I_PD
- Analog input current I_AnalogIn
- Total synaptic current (1+2) I_Synapse
- System time in microseconds currentMicros

Removing some of these from the data logging can increase model speed. If all are removed (no communication with computer), the model refresh rate more than doubles to ~1,000 Hz (loop time ~1 ms).For convenience, we pre-configured a simple option to remove them in several instances through the global variable FastMode near the top of the script. At default (=0), all 9 parameters are logged, and the model runs at ~420 Hz. If set to 1, 2, or 3 the model starts dropping the later parameters, as explained in the script itself (1.57, 1.22, 1.0ms, respectively, corresponding to 633, 819 and 1000 Hz)

(Note: The analysis scripts (Python/Matlab) provided assume that system time, which is always needed for time-accurate plotting, is stored in the 9th column (i.e. 8, with 0 indexing). However, in FastMode=1 or =2, this jumps to column 4 and 2, respectively, so if these modes are used for logging the pre-processing scripts should be updated to reflect this.)

Analog Read/Write operations are called several times within the main loop, either reading the state of a dial, the photodiode or the analog in port (3). Analog write operations drive the Analog out port (5) and the onboard LED. The user could choose to simply disable one or more of these functions. A short explanation how one might go about this is included in the sketch itself. Advanced users may also consider not disabling them, but rather calling them less frequently (e.g. only every 10th time the model loops). While this should principally work, note that it would selectively slow down the instances in which the call was executed, so the model would not run at a constant speed but instead jump a bit. However, this may not be a big problem depending on the intended use. Notably, in the Spikeling 2.0 version (see below) we already down-scaled the Analog read bit depth to 16 to speed them up a little (Using AnalogReadHelper)

Timestep_ms. Finally, the user can also alter the timestep_ms global variable near the top of the script. Increasing this will speed up the Izhikevich model in a linear dependence (i.e. doubling timestep_ms will double model speed) but run risk that it skips spikes and generate weird-looking waveforms. Vice versa, decreasing it will generate “nicer” waveforms, but at further cost to speed. Notably, this will only affect the actual spike model, not the whole script.

## Spikeling 2.0

We are currently working on a new version of Spikeling (2.0) that will feature a range of improvements, including perhaps most notably the possibility to connect a TFT colour display for live display of the model output.

The new version replaces the low-cost Arduino Nano microcontroller of Spikeling 1.0 with the more modern ESP8266 (e.g. https://www.adafruit.com/product/2471). First tests indicate that the ESP8266 (by itself, without TFT screen connected) executes the Izhikevich model at about 5-10 times the speed of Spikeling 1.0 (3.7 kHz at full output, compared to 420 Hz for Spikeling 1). This can be pushed to near “realtime” with fastmode enabled (see above), such that each loop execution round approaches 0.1 ms, which is the iteration step that the Izhikevich model is set to. Of course, it is possible (up to a point) to lower that timestep_ms parameter to match the the actual execution step to achieve “realtime”.

With the screen connected, Spikeling 2.0 speed drops to about the same speed as Spikeling 1.0.

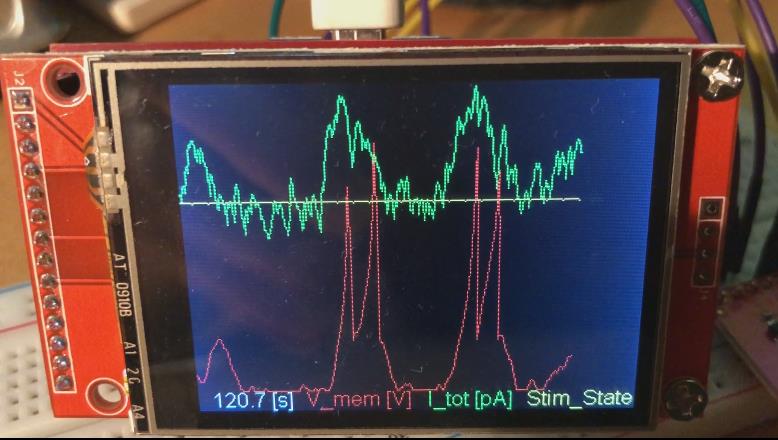
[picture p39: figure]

Spikeling 2.0 prototype with TFT screen connected

In addition to either offering speed enhancements or the option for a TFT screen, the new microcontroller is also WiFi enabled which presents the possibility to do remote-data logging without need for a dedicated USB cable. Notably, to connect the ESP8266 to the dials and photodiode used in Spikeling 1.0 requires addition of a dedicated integrated circuit (IC) chip such as the MCP3008 (e.g. https://www.adafruit.com/product/856).

The ESP8266 Wifi Colour Display Kit sold by ThingPulse, which includes the ESP8266 itself, a breakout board and the TFT screen:

https://thingpulse.com/product/esp8266-wifi-color-display-kit-2-4/ (https://thingpulse.com/product/esp8266-wifi-color-display-kit-2-4/)

At time of writing, Spikeling 2.0 is under

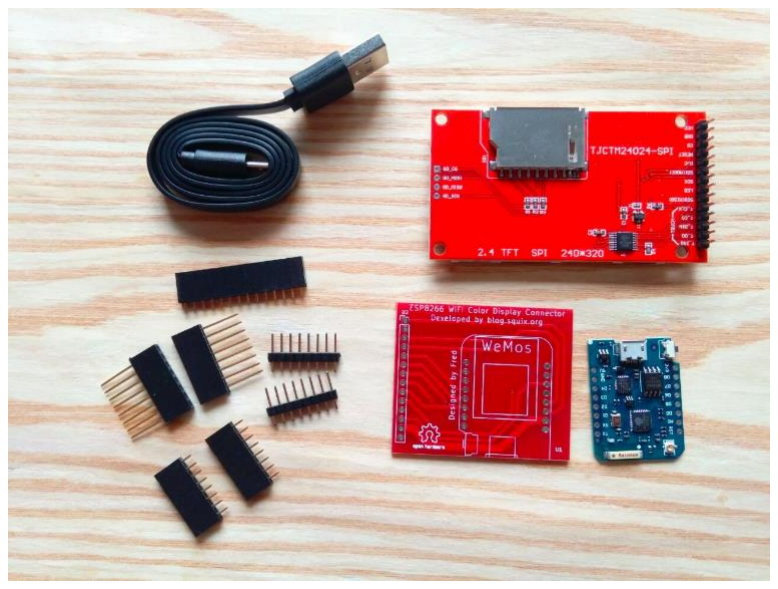
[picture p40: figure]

ongoing development. All documentation to its current state can be found on the Spikeling GitHub: https://github.com/BadenLab/Spikeling. However, the Arduino code running Spikeling

1.0 has already been set-up to work with either version, with one required user alteration depending on which board is used:

//#include "SettingsArduino.h" decommented, so disabled

#include "SettingsESP.h" currently Spikeling 2.0 is enabled.

To switch, just move the // (decomment) to the other line

## Spikeling Exercises

### Resting membrane potential

In the absence of a stimulus, the Spikeling rests at -70 mV and should only spike sporadically. Resting membrane voltage (Vm) can be set indirectly with bottom-most dial (dial 4), which sets a constant input current. For now, on the oscilloscope we are only interested in the membrane potential trace (the red one) and the current trace (the green one). The red LED on the board also tracks Vm, and flashes with each spike which should also be accompanied by a “click”. Electrophysiologists often connect a speaker to their recording of membrane voltage to get a direct audio feedback of what the neuron might respond to.

Task 1: What happens when you increase or decrease the static input current?

You should observe that increasing the static input current drives Vm towards and beyond spike threshold. As you keep driving Vm upwards, you will elicit progressively higher spike rates. This is the simplest of all neuronal codes - the intensity of a stimulus (here, simply the increased input current) is encoded in the frequency of spikes. Imagine you are the postsynaptic neuron and all you see is this spike pattern – you could easily infer from seeing more spikes in close succession that the input to the presynaptic neuron has probably increased. Most spiking neurons use this rate code to signal input intensity.

On the screen, note that each spike is preceded by a shallow rise in Vm and followed by a brief dip below starting levels. This dip is the refractory period of the neuron. During this time, generating another spike is particularly difficult. At the extreme low point of Vm it is impossible to generate a spike, which in a biological neurons is because the sodium channels are blocked (not just closed). This absolute refractory time, together with the duration of the spike itself (1-2 ms) sets a limit on the maximum spike rate possible. In an average neuron, the absolute refractory period is a few milliseconds, and thus the maximal spike rate of most neurons is ~100-200 Hz. Some specialised neurons can go a bit higher, but kHz range is out of question. This means that, by using a single spiking neuron, it is impossible to faithfully encode a time-varying stimulus above this frequency. However, there are a few tricks around this problem that the nervous system can use. We will pick up on this point later.

Task 2: What happens when you dial current up and then wait a few seconds?

If you drive up input current and leave it there for a few seconds, you should observe that spike rate first increases, but then will taper off to some new basal rate of activity which will be higher than the original rate (rate code), but lower than the peak rate. This is an example of adaptation. Neurons respond to a change in the input not only by firing more or fewer spikes, but in addition by adjusting their sensitivity to further changes based on recent stimulus history. This is a fundamental property of neurons that allows them to extend their operating range, and to stay responsive to further changes in subsequent inputs.

Task 3: Does a rapid and a slow current increase generate the same voltage response?

As you increase input current slowly or rapidly, you should observe that you can reach different peak spike rates. A rapid increase in input current is a much more effective way to trigger multiple spikes in close succession. This is again because of adaptation. If you change input current fast enough, the neuron does not have time to adapt and therefore fires vigorously at first. If you change input current slowly enough, you should be able to drive it quite high without eliciting many extra spikes as it adapts while you slowly ramp up the current. This means that not only the absolute level of a stimulus can be encoded by a neuron, by also the rate of change. Note that this creates ambiguity in the code, which is one important reason for the need of parallelisation. This means that if you want to read both absolute levels of a stimulus and its rate of change, you may need two neurons with different properties.

NB: The fact that the speed of change in the input is encoded in a neuron’s firing also means that that spike thresholds are not fixed. Depending how quickly you stimulate a neuron, it can start firing at different Vm values!

### External Stimulation: Light

Spikeling has a built-in photodiode – the clear dome-shaped object in the lower left corner. This functions like a “mini solar-panel”. If you shine light at it, it generates a tiny voltage, and Spikeling is programmed to react to this voltage. Increasing the amount of light hitting the photodiode drives a depolarising current, just like the static input current dial did (above).

Task 4: Shine some light at the photodiode e.g. using a torch or by holding it to the room light. Observe both the current (green) and the voltage trace (red). Can you get the cell to spike in response to light? Does it spike every time you hold it into the light?

Shining light at the photodiode should cause a brief increase in the driving current, which will be mirrored by the membrane voltage. If the light intensity is high enough, you should be able to generate spike(s). However, if the light is weak, or presented only for a very short amount of time, you will probably not drive a spike. This is an example of how neurons can use a spike threshold to only report the presence of a stimulus if it is of a certain amplitude and minimum duration. However, do note that even if there is no spike generated, the membrane voltage will still react to most changes in the light. This “sub-threshold” activity is fundamental to many neuronal computations. We will return to this point later.

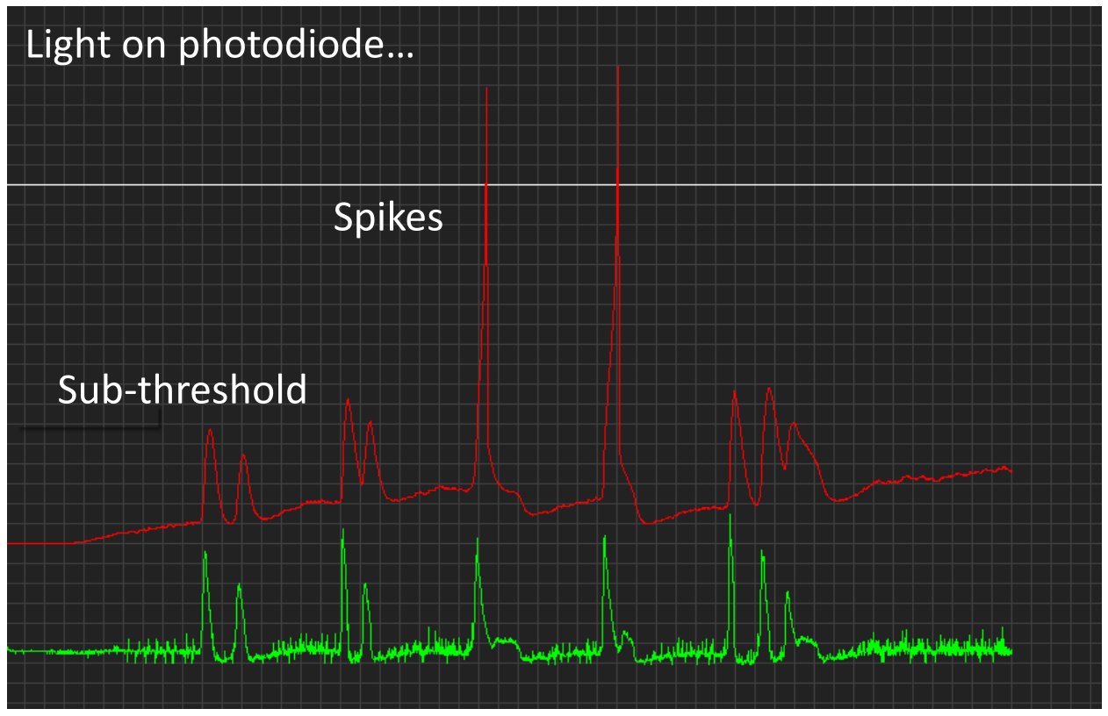
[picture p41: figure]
Spikes; Sub-threshold; Light on photodiode…

Task 5: Turn the static input current dial up so that Spikeling generates a few spikes per second, and then shine some steady light at it. You should observe that the spike rate increases a lot at first, but then settles to an intermediate spike rate (just as before when you increased just the Vm dial). Now, suddenly remove the light. What happens?

You should observe that when you remove the light, membrane voltage will drop not just back to baseline levels, but below baseline for a short period of time. As it drops below baseline, it will probably result in a brief gap in spikes. This is an example of how a sudden absence in a stimulus that the system has adapted to can be encoded by the neuron by the absence of expected spikes. However, the salience of this code is low. For a postsynaptic neuron reading this signal, it is much easier to respond to the presence of an unexpected spike, rather than the absence of an expected one. (How could you turn the absence of an expected signal into the presence of an unexpected one?)

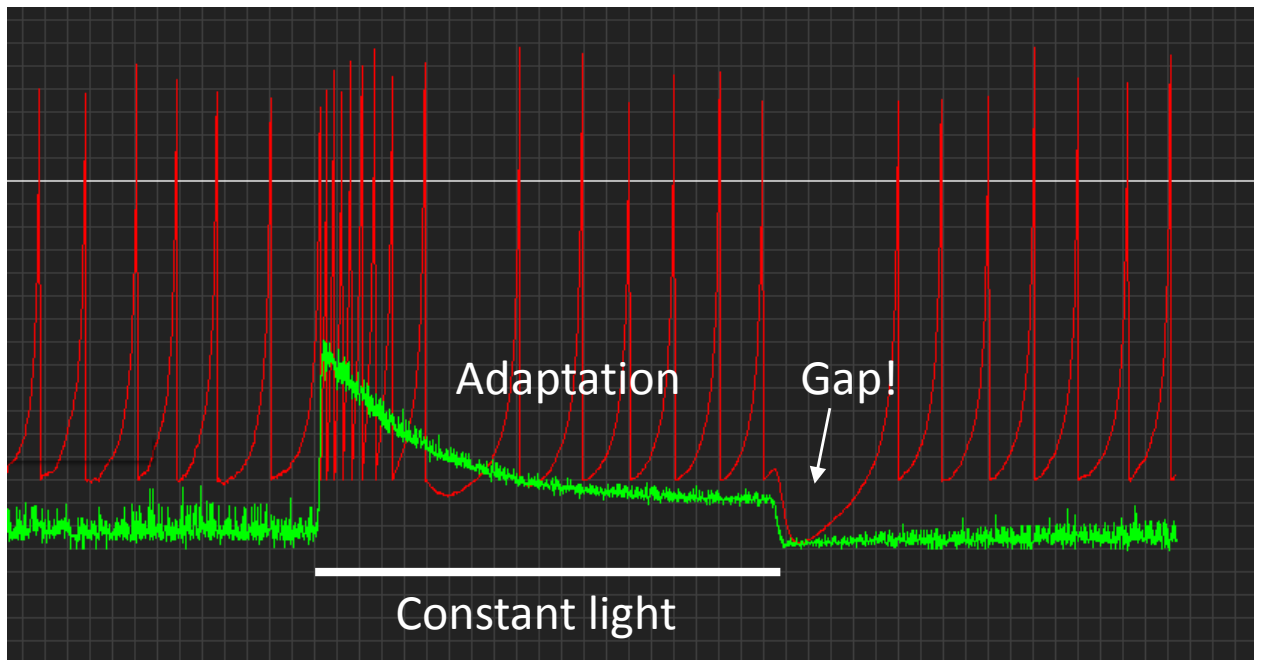
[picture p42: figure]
Constant light; Adaptation; Gap!

## Switching spike-modes

Spikeling comes with multiple preprogrammed behaviours, which can be cycled through with the on-board button (the big black one). If you press the button from reset state, a little LED on the Arduino should light up twice. This means that Spikeling is now in “Mode 2”. If you press it again, it should blink 3 times (Mode 3) and so on. If you get to the end (Mode 5), it will cycle back to 1. You can always jump to 1 by resetting the Arduino (the little white button on the Arduino itself).

The preprogrammed modes are as follows:

1) Regular spiking neuron, slow adapting photodiode (“Sustained ON”)
2) Bursting neuron, fast adapting inverted photodiode (“Transient Bursting OFF”)
3) Fast spiking neuron, slow adapting inverted photodiode (“Sustained OFF”)
4) “Chattering“ neuron, fast adapting photodiode (“Transient ON“)
5) High threshold firing, slow adapting photodiode (“Sustained ON II”)

For now, let’s just focus on the first 3 modes. Compare the above exercises on resting membrane voltage and photodiode stimulation in different spike modes.

Task 6: Comparing Modes 1and 2: What are the differences when you depolarise the neurons using the static input current (dial 4) and when you pass a torch over the diode?

The baseline spiking behaviours, the speed at which the response to photodiode stimulation decays, and the polarity of the light response are all different. For example, if you continuously shine light at Spikeling in mode 1, it will adapt slowly. If you do the same for mode 2, it will adapt a lot faster and to a stronger degree, the current is inverted. This is an example of a “transient OFF” (mode 2) and a “sustained ON” neuron (mode 1). In the nervous system the transience of a neuron is one fundamental ingredient in generating different functions. For example, transient neurons are usually good at encoding the onset of a stimulus, but not very useful in signalling when that stimulus stops. In contrast, the sustained neuron encodes both events quite reliably, but the energetic cost is higher (it needs more spikes) and the information content per spike is lower. Neurons are amongst the most energetically costly cells in the body. They are also amongst the most fragile if energy supply is low (for example during a stroke!). Most neurons will die after even a few seconds to minutes of oxygen deprivation. Accordingly, when considering neurons and neuronal networks, it can often be instructive to consider the energy costs associated with a particular computation. If you can implement the same computation using fewer spikes, or fewer neurons, that is probably a good thing, and most of the time it is what the brain will have evolved to do. Accordingly, it is not always about setting up the “best” computation, often it is about building the cheapest system that still works with adequate reliability.

Another reason for using a transient neuron is that after it signals the start of an event, it is rapidly “ready” to signal the start of another event. If a transient neuron spikes twice, it probably means there were two events. If a sustained neuron spikes twice, it could mean there are 2 events or that there was one event which is still ongoing. Accordingly, the sustained neuron’s code is usually more ambiguous. Ambiguity in coding is almost always a bad thing. It reduces the information content per spike (costly!) and it usually means you need additional neurons to resolve the ambiguity (also costly).

# Light on photodiode – sustained neuron, slow spiking

Task 7: Compare Modes 1 and 3 at the level of the photoresponse and during current injection. What sets them apart?

In Mode 3, the spike threshold is lower and the refractory period following a spike is shorter. This neuron will do most things that the Mode 1 neuron will do, but it will use more spikes. In addition, its photo-response is inverted (“sustained Off cell”). While energetically costly, sometimes you need more spikes. For example, for a rate code to encode as much information as possible, the bigger the rate-range is that the neuron can cover, the more finely resolved can you encode signals using the frequency of spikes. One often used example here are projection neurons of auditory systems.

Another advantage of using a neuron that can reach high spike rates is that negative coding becomes more useful. If the basal firing rate of a neuron is high, a reduction in this rate (for example due to the sudden absence of a depolarising stimulus, or due to the addition of an inhibitory input) can still be readily read out by postsynaptic neurons. This is easily illustrated if you repeat an experiment from above: Set the basal spike rate to a few spikes per seconds using the static input current dial, then iteratively shine a constant light at the photodiode and then remove the light. Each time you shine light, the high “dark” spike rate should drop to a new, lower spike rate, and this change should be much more obvious (and inverted) if you use the fast spiking neuron from Mode 3 compared to the regular spiking Mode 1 neuron.

### The “Self-Stimulator”

From the exercises with the torch, you will have noticed that it is difficult to reproduce the same stimulus from trial to trial. To help you with this, Spikeling comes with an option to “stimulate itself” by generating a defined light output. Port 1, by default, is defined as an output port which delivers 5V pulses at different intervals depending on the mode. Connect a BNC cable to this port, and on the other end connect the extra BNC-cap with an LED attached. You should now see that the LED lights up in regular intervals. Attach this LED to the top of the photodiode (e.g. with a bit of tape or a ring of paper or the 3D printable holder provided) such that whenever the stimulus LED lights up you can clearly see an increase in the input current on the oscilloscope. In addition, configure the 3rd trace on the oscilloscope (blue trace) so that you can see it switch between 0 and 1 to indicate the state of the stimulus.

[Note, instead of using an LED to self-stimulate via the photodiode, you can cut out the middle man and inject by connecting the cable from port 1 to the analog in port (3), thereby driving Spikeling directly with square pulses. For this crank up dial 2 as well to set the gain (amplitude) of this connection].

You should now have 3 traces on the screen: The red membrane potential, the green input current, and the blue stimulus. If you cannot see the stimulus, the y-axis is probably configured incorrectly – use the buttons as described before to adjust the scaling of the blue trace. Every time the stimulus is high, the green trace and therefore the red trace should both respond with an increase in turn. This set-up will let you explore the response properties of Spikeling in a more controlled manner.

For now, let’s focus on Modes 1 and 2. For both, the stimulus LED switches on and off at regular intervals, such that it is on and off exactly half of the time (the technical term is “50% duty cycle”). If you now turn the top-most dial (1) away from resting mid-position, the frequency of this flicker will change accordingly.

Task 8. Stimulate mode 1 at a constant speed (e.g. 1 Hz) and play with the static input current (dial 4). Can you get Spikeling to reliably spike throughout stimulus presentation, but not spike in the absence of a stimulus? How precisely can you encode the end of the stimulus with spikes?

You will probably find that while it is easy to set the neuron to only spike during a stimulus, it is much more difficult to tune it to reliably fire a last spike just before the stimulus ends. This problem will get worse the longer-lasting the stimulus, as the photodiode will adapt just naturally the dropping spike rate. Moreover, any one setting of speed will only “work” with a limited range of settings of static depolarisation. This comes back to the point before – it is much easier to encode the presence of an event with the presence of a spike, than with the absence of an expected spike.

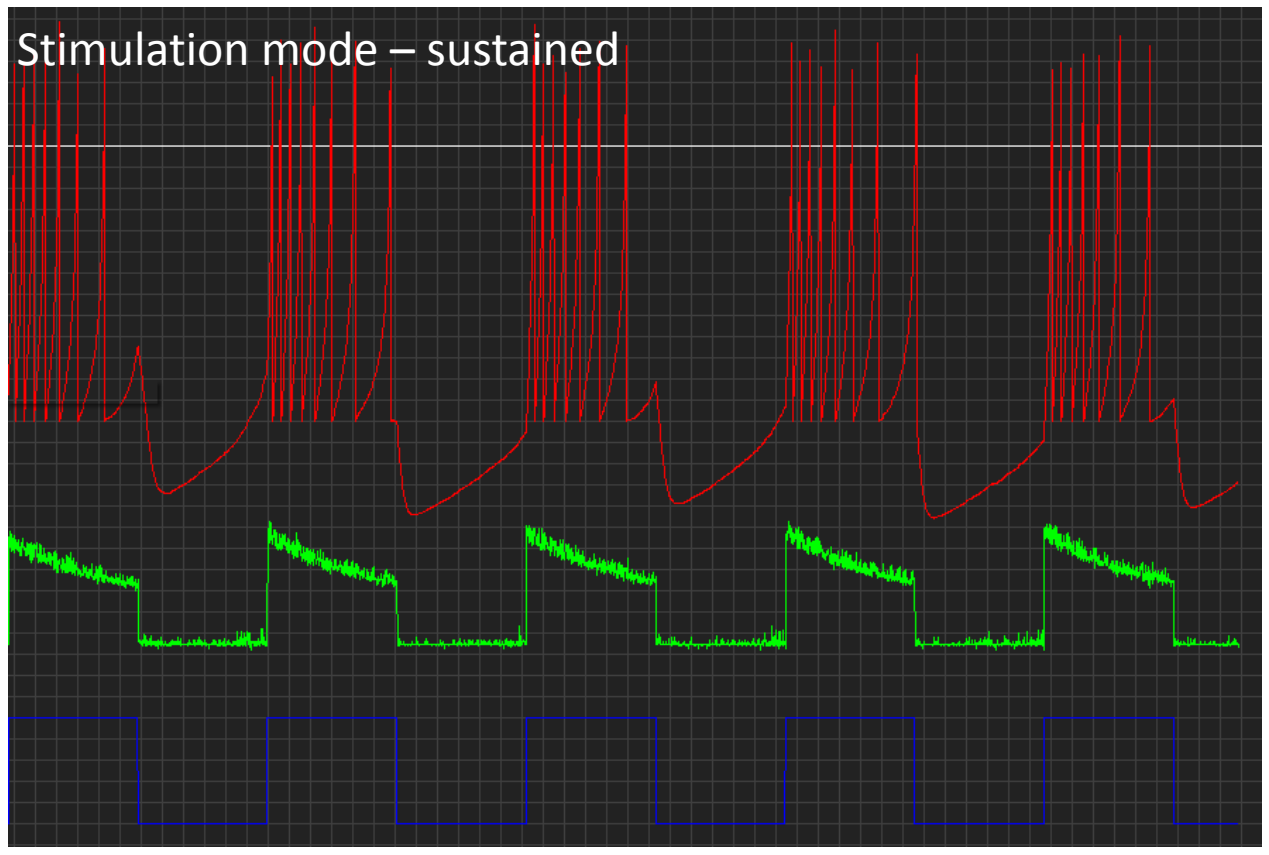
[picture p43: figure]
Stimulation mode – sustained

Task 9. Stimulate mode 2 with steps of light elicited at different speeds. Now, play with the static input current in each mode. Can you get Spikeling to reliably burst during stimulus offset in transient mode 2?

You probably found that it is quite easy to set the transient neuron to encode the offset with a burst of spikes, simply because this is an intrinsically bursting neuron. However, depending on the stimulus speed, you may find that this behaviour breaks down quickly. It is however possible to “entrain” this neuron (synchronise to the stimulus) using light within a limited range of stimulus rates. As such, as a primary sensory neuron reporting the offset of a step of light, this neuron is not great – as it will also spike simply if you wait long enough assuming it is slightly depolarised. However, if you had an inherently rhythmical stimulus (for example a sensory mechanoreceptor neuron in the leg firing during walking) and you wanted to synchronise the activity of other neurons to this stimulus, such a burst-entrainment can be very useful!

Task 11: Now, start playing with the speed of the stimulus while adjusting the static input current as required for all modes. How fast can you go with either the transient or the sustained neurons until you start observing spike failures?

You will probably find that all neurons do a reasonable job in encoding each event with at least one spike until about 2-3 Hz, but that at higher frequencies they will start to fail spiking every now and then despite the presence of a stimulus. As Spikeling is set up, it will probably do a little better using the sustained neurons. This is not inevitable – if one were to change the spiking parameters a bit, it would be possible to make the transient neuron more reliable. More importantly, the photodiode, the spike mode settings and the static input current all come into play when determining thefrequency limit at which a neuron can follow a time-varying stimulus. As such, “tuning” a neuron’s response preference to a desired fluctuating input requires setting a myriad of properties. The nervous system utilises this to tune each neuron to a specific range of input statistics, and, indeed, to adjust these settings as the task at hand requires.

Task 12. Pick one mode and keep increasing the speed of the stimulus almost as fast as it will go and set the static input current such that it only spikes occasionally. What do these spikes encode?

If you set Spikeling into a regime where most stimuli do not trigger a spike, you will notice that nonetheless each stimulus drives a clear subthreshold response. If you now look carefully at the timing of each spike that is elicited, you will likely find that this time is fairly well “phase-locked” to the onset of a stimulus phase. In isolation, this is not a particularly useful property of neurons. But imagine you had 10 such neurons, each spiking unreliably every 5-10 stimulus phases. If you sum the input from these 10 neurons using a larger, postsynaptic neuron, you could fully reconstruct the original stimulus train even though no single input neuron encodes that information. This is called a “volley code”, and it is one of the most important tricks that neuronal networks use to encode a fast time-varying stimulus that exceeds the speed that any one neuron can encode. For example, in auditory systems, the stimulus frequency can easily reach the kHz range which no neuron can possibly follow, as discussed above. Nonetheless, if you record any one neuron’s firing in response to such a stimulus you will probably find that the timing of each spike is exquisitely well phase-locked to the stimulus, such that if you had a few 100 of these neurons you could precisely reconstruct the original input.

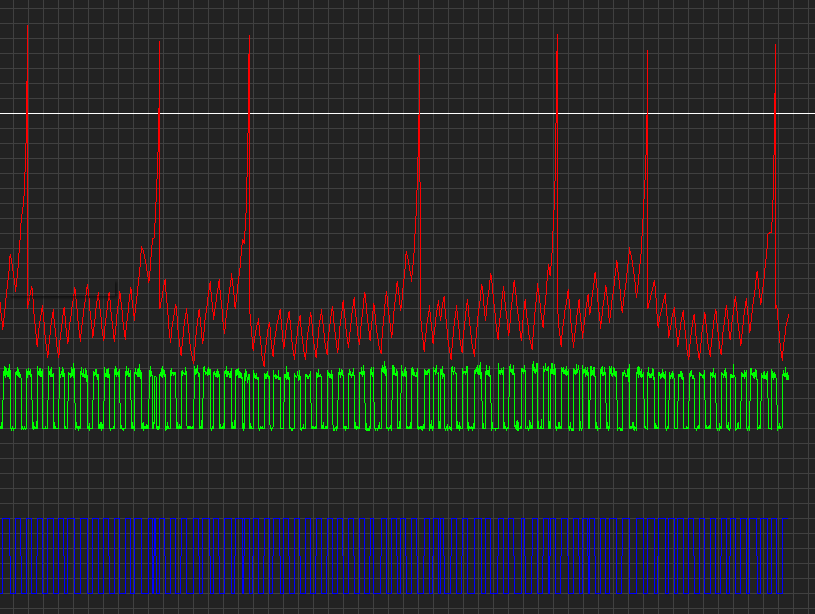
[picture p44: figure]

Task 13. Decrease the static input current until no more spikes are triggered. Observe the membrane potential as you increase the stimulus speed. Can you get Vm to fail following the stimulus?

You will probably find that up to the speed that Spikeling can stimulate, Vm comfortably tracks the stimulus (while spikes do not). This is a fundamental property of neurons. The subthreshold response of a neuron is almost always better at following stimuli than the spike response. As discussed above, eliciting a spike and resetting the neuron to be ready to fire the next spike takes time (in Spikeling, this takes >10 ms, some real neurons can reset after 1-2 ms but not faster). If you do not need to generate a spike, this limitation is dramatically reduced, and you can follow stimuli much better, and much more accurately (also in amplitude). Of course, not all neurons spike. Spiking consumes energy and is a relatively costly and inefficient way of conveying information, so if neurons can avoid using spikes, they will. For example, one fundamental reason to use spikes is to rapidly cover large distances. If you have a big brain (like us), you need to use a spike to send a signal from one end to the other. Depending on a neuron’s electrotonic properties, a graded signal would just decay with

# Stimulation mode

distance and be lost in the noise ~100 microns from the origin. Spikes are regenerative and propagate over distance, allowing signals to be transmitted over longer distances (stubbing your toe). Two disadvantages of signalling with spikes is that you truncate the message, both in time (refractory period) and in amplitude (threshold). So, if the distance to be covered is small, using spikes is usually avoided. For example, the tiny nematode worm C.elegans barely uses any spike at all. The animal is so teeny that all distances are small. Similarly, many neurons in the Drosophila brain don’t spike. Other’s use a “mix” of spiking and graded processing. In vertebrates, the same thing happens in some neurons. For example, in the retina, only about half of the neurons use spikes. Photoreceptors, for example, generally don’t use spikes. Ganglion cells, on the other hand, connect the eye to the brain via the optic nerve – so there is no way around it, those neurons have to spike.

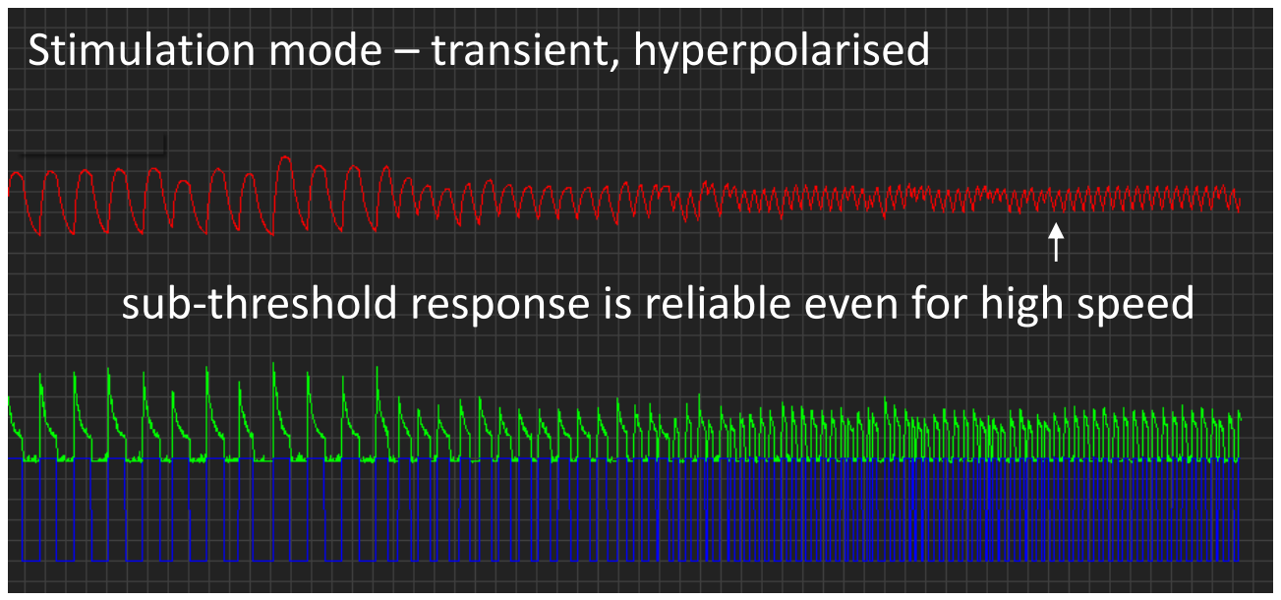
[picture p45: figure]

### Noise

Real neurons are noisy. Sources of noise include synaptic inputs, receptor noise, thermal noise or even noise associated with the physical world that an animal inhabits. Accordingly, one major challenge that all neurons face to at least some degree is how to detect the meaningful “signal” in the background of meaningless “noise”. So far, we have been working at low noise but Spikeling provides the option to add different level noise to any operation – for this, turn the second dial from the bottom (dial 3). At mid-point (reset-state) and below that, no noise is added, but above that position increasing the dial will linearly increase a “noisy current” which adds to the total current shown in the green trace.

Task 14. Turn up the noise dial, while keeping the mean input current roughly centred around 0 (use static input current dial to offset this if necessary). What happens to membrane voltage as you add more and more noise?

At first, increasing the noise current will only affect the baseline noise of membrane voltage, which will resemble a low-pass filtered version of the input noise. This is the first “trick” used by all neurons to dampen high frequency components in the noise – the membrane potential simply cannot track the fastest transients in the input current and therefore “automatically”

# Stimulation mode – transient, hyperpolarised

# sub-threshold response is reliable even for high speed

filters them out. As you keep increasing the noise level, you should be able to elicit spikes. These noise-driven spikes are almost always a bad thing. They do not convey any information (thus wasted energy), and to make things worse, they confound any message that the neuron is aiming to encode using spikes. Accordingly, neurons often aim to keep the spike threshold high enough such that the noise they have to deal with by itself very rarely triggers a spike. Accordingly, spike generation can be used as a powerful noise filter.

Task 15. Turn the noise dial (3) back down and look at the baseline. Now cover the photodiode (e.g. with your hand). What happens?

You will probably find that when you cover the photodiode, the baseline noise that we had all along in the above exercises decreases. Clearly, the photodiode is introducing noise to the system! In this case this is high frequency noise that largely gets smoothed at the level of membrane potential. All sensory processes, whether electronic as here, or in biology, necessarily introduce noise - simply because the apparatus to pick up the desired physical stimulus is never perfect. In vision, for example, the stimulus (photons) is absorbed inside an opsin-type protein by a chromophore. As the photon arrives, it photoisomerises the chromophore and thereby sets a biochemical cascade into action that ultimately results in the opening of ion channels. However, the isomerisation event can also occur “spontaneously” – or rather driven by heat. As such, all sensory systems are noisy, and nervous systems have evolved a wide range of little tricks to overcome this problem. Here, spike generation or the

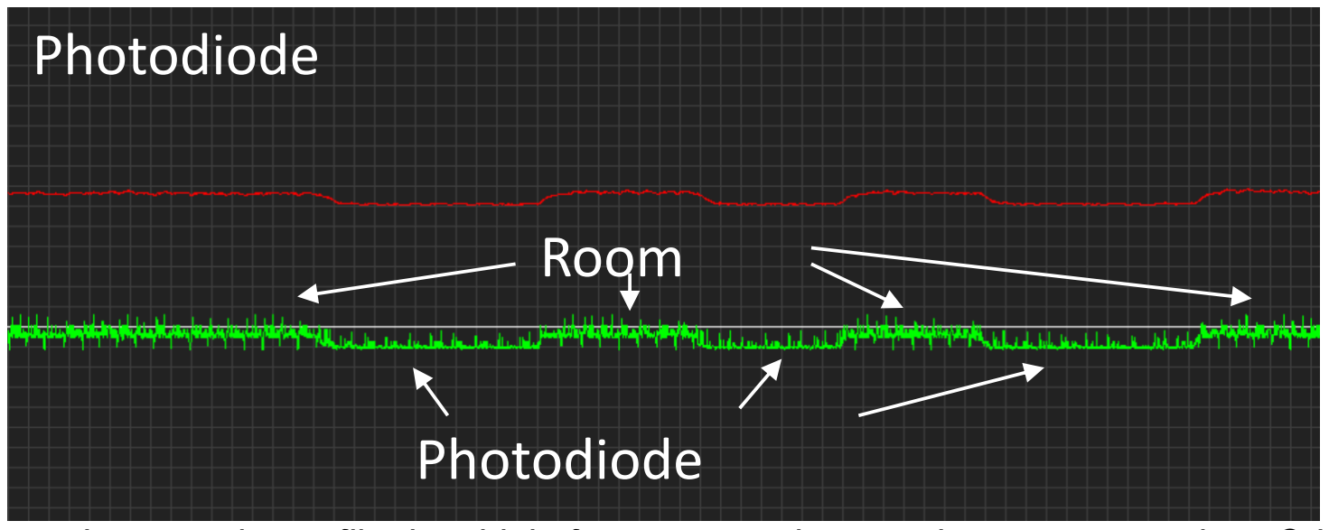
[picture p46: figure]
Photodiode; Room

membrane voltage filtering high frequency noise are but two examples. Others include summation (having multiple neurons signal the same thing and then adding the signal up in a postsynaptic neuron) and temporal “smearing” (e.g. by using slow receptor cascades) are two further examples. There are many more.

Task 16. Compare two modes of your choice to see how each deals with noise. Which one would you use to reliably trigger spikes in response to each stimulus? Which one would you choose to make sure spikes are only elicited at the start of a stimulus (even if sometimes they fail)?

You will probably find that the sustained neurons will be quite good at reliably firing at least one spike in response to each stimulus. However, the number and timing of each spike per stimulus cycle will likely vary a lot. In contrast, the transient ON neuron might fail every now and then to report the presence of the stimulus, but if there is a spike, it usually means that it was preceded by a stimulus. Spikes from such a neuron are highly informative, but unreliable. How can nervous systems make this mechanism more reliable?

### Building networks

Multiple Spikelings can talk to each other using the Digital Out and Synapse 2 BNC ports (or Synapse 1, if enabled in the Arduino code, default is disabled). The idea is that the Digital Out port of one Spikeling (port 4) conveys only spike events, which can be fed into the Synapse 2 input ports of a second Spikeling (port 2). The gain of each synapse can be regulated using the corresponding dial on the other side of the board (dial 2). At reset state, the gain is zero (so the synapse will not do anything if it receives a spike). If you turn the dial up, you get an excitatory synapse. If you turn it below midpoint, you get an inhibitory one.

Try this now: Reset two Spikelings and take a BNC lead to connect the Digital Out port of one (presynaptic) to the Synapse 2 in port of the second. Connect the second Spikeling (postsynaptic) to the PC via the USB cable so that we can read its activity on the oscilloscope. The presynaptic Spikeling does not need to be connected– but it does need to be powered, either using a 9V battery or by plugging the USB into a power socket).

Task 17. In this configuration (above) increase the static input current on the presynaptic neuron so that it continuously fires a few spikes per second. Now observe what happens to the postsynaptic neuron as you turn up the synapse 2 dial to increase its gain.

You should observe that if the dial is at midpoint, nothing much happens – the spikes from the presynaptic Spikeling are still received, but they do not drive any current in the postsynaptic neuron. (Note that you can see the incoming spikes if you open a second oscilloscope – Synapse 2 spikes are on channel 5, so the green channel of the second oscilloscope). Now as you increase the gain you should see that each spike triggers small depolarising current which decays back to baseline within a few 100 ms. If spikes come in a sufficient rate, this input current will start to integrate between successive incoming spikes to further depolarise the cell. If it reaches threshold, spikes should be triggered. The fact that the synaptic current outlasts the duration of the incoming spike is a fundamental ingredient to neuronal processing. It means neurons can “count and calculate” using synapses – sort

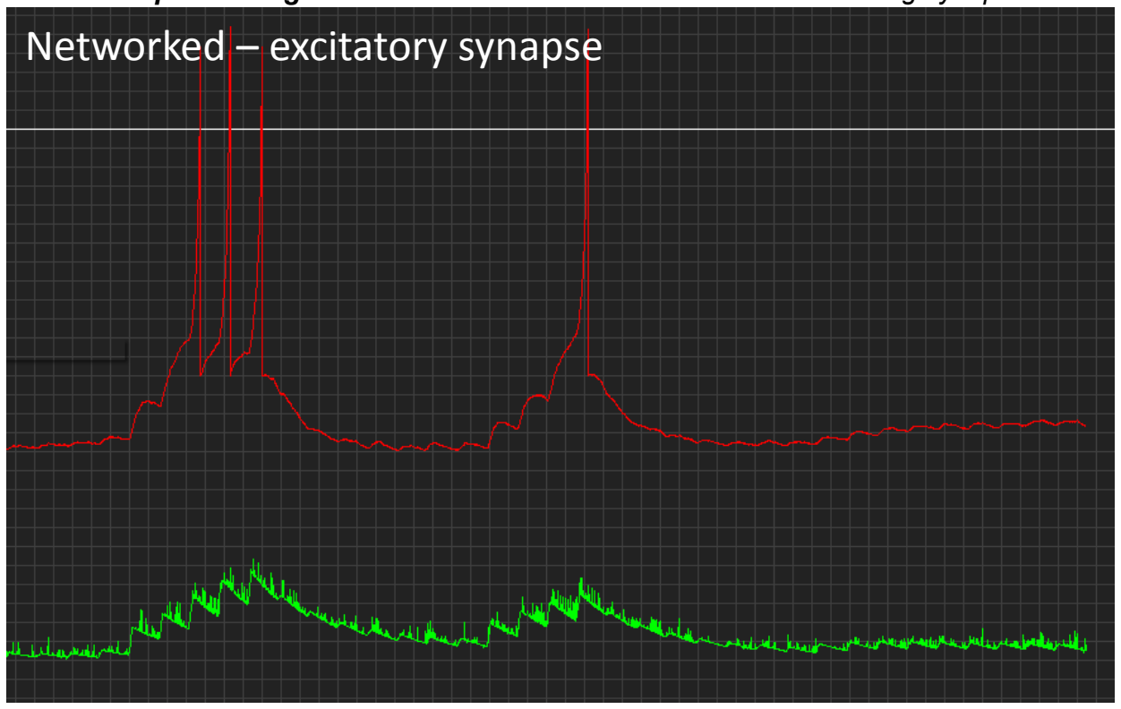
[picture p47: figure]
Networked – excitatory synapse

of, anyway. For example, suppose for a particular computation it is important to know that there was not just one, but two spikes fired within close succession. This could be easily computed by setting the excitatory gain of the connecting synapse(s) such that a single spike does not drive the postsynaptic neuron to threshold, but that if two spikes arrive in close succession, threshold is reached and thus the neuron fires. The same logic also applies across different synapses, which allows the implementation of coincidence detection.

Task 18. Now turn the Synapse 2 dial below midpoint. What happens?

You should observe that now each presynaptic spike drives a hyperpolarising current in the postsynaptic neuron. This is intended to mimic an inhibitory connection. In case of Spikeling, this connection is programmed to be mirror symmetric to the excitatory connection in every way. However, in reality the gain and time courses of synaptic events can vary dramatically and are another fundamental ingredient to building computational networks. For the purpose of this tutorial, the time-course of the synapses is fixed. However, advanced users can change this in the annotated Arduino code.

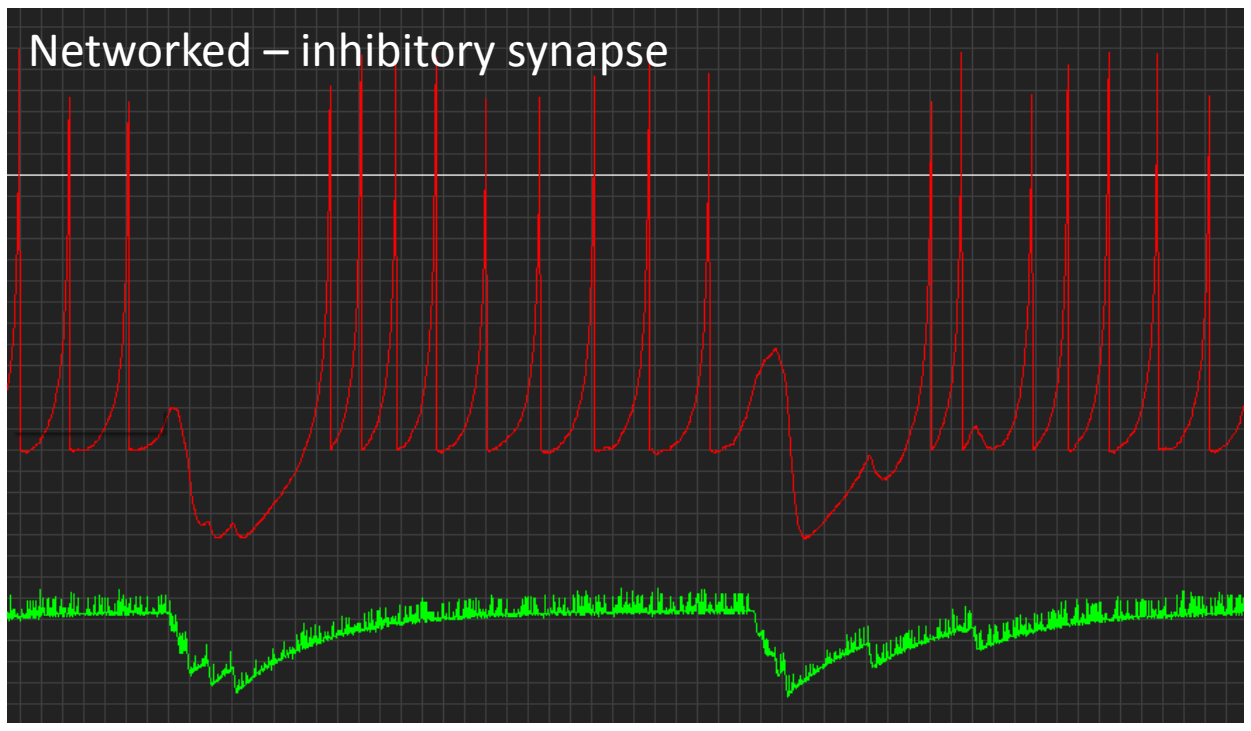
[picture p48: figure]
Networked – inhibitory synapse

Task 19. Put the postsynaptic neuron’s stimulus LED above the photodiode as before, but now hyperpolarise it using the static input dial such that the LED alone does not elicit spikes. On the presynaptic neuron, make sure that it does not fire spikes at rest, and configure its input to be weakly excitatory. Now take a torch to stimulate the photodiode on the presynaptic neuron and thereby make it spike. Can you get the postsynaptic neuron to spike?

Neither the stimulus light nor the synaptic excitation alone should be sufficient to drive a spike in the postsynaptic neuron. However, if you make the presynaptic neuron spike using the torch at the same time as the stimulus comes on, the two excitatory inputs will summate and you should be able to reach threshold. This is an example of a coincidence detector. If the postsynaptic neuron spikes, it means that both the stimulus (stimulator) AND the presynaptic stimulus (torch) were both active at the same time.

One “famous” coincidence detector is used in auditory systems for comparing the signal between two ears. Imagine sound coming from your left. Because sound travels slowly (330 m/s) it will arrive at your left earhole about a millisecond before it arrives at your right earhole. Neurons in each ear’s cochlea will spike as soon as the sound arrives and send that signal to the brainstem where the signals from the two ears are combined. Here there are bilateral neurons that receive inputs from both ears. These are the coincidence detectors. If the sound came from the left, the spike from the left ear comes in before the spike from the right ear and its associated postsynaptic current will decay rapidly, such that it does not overlap with the current triggered by a spike from the right ear. As a result, the central neuron will not spike. However, if the sound comes from e.g. straight ahead, it will reach both ears are the same time which in turn means that the left and right spike inputs to the central neuron will coincide and drive a postsynaptic spike. Such as central neuron therefore encodes the direction of sound. If we now slightly offset the speed by which the spikes travel, or implement delays of initial spike generation in either ear, we can build a neuron that is selective for any sound direction in the azimuth plane (horizontally around the head).

This kind of logic expands into a multitude of computational operations. The above coincidence detector is perhaps the simplest of logical operations: an “AND” gate. This means that Input 1 AND Input 2 need to be “high” for the spike to be triggered. Another logical operation is an “OR” gate – Input 1 OR Input 2 need to be high. This is easily achieved by increasing the synaptic gain such that one neuron alone can drive the postsynaptic spike. There are many such logical operations (e.g. NOR, XOR, XNOR), which can be thought of a computational building blocks of electronics and neuronal networks alike. If you simulate many neurons in a computer, it is straightforward to implement any of these logical gates. We can try to set-up some of these using Spikeling. For example, how might you build an “inverse conditional” – i.e. a neuron that only fires if input 1 is high, unless input 2 is also high? How might you build a NOR gate (only fires when both Inputs 1 and 2 are “low”). How might you build an NAND gate (fires always except when both 1 and 2 are “high”). If you have more than two Spikelings at hand, try playing with these a bit. What kind of computations can you implement? (one useful reference for logical gates and their implementation and background can be found on Wikipedia: https://en.wikipedia.org/wiki/Logical_connective).

Note that in their “pure form”, logical operations are Boolean (“True or False, no intermediate state is possible”). But neurons are noisy, so not all operations are equally “easy” to implement! (all are possible though).

Task 20. Using what you have learnt(!) (and two Spikelings): Can you build an “OFF neuron” using only ON neurons as the input?

One way of doing this is by setting the postsynaptic neuron at a high resting potential such that it continuously generates spikes. Now take a presynaptic neuron that responds to the light in an “On fashion” and connect it to inhibit the continuously active cell. If you tune the inputs right, you should be able to generate something like the below:

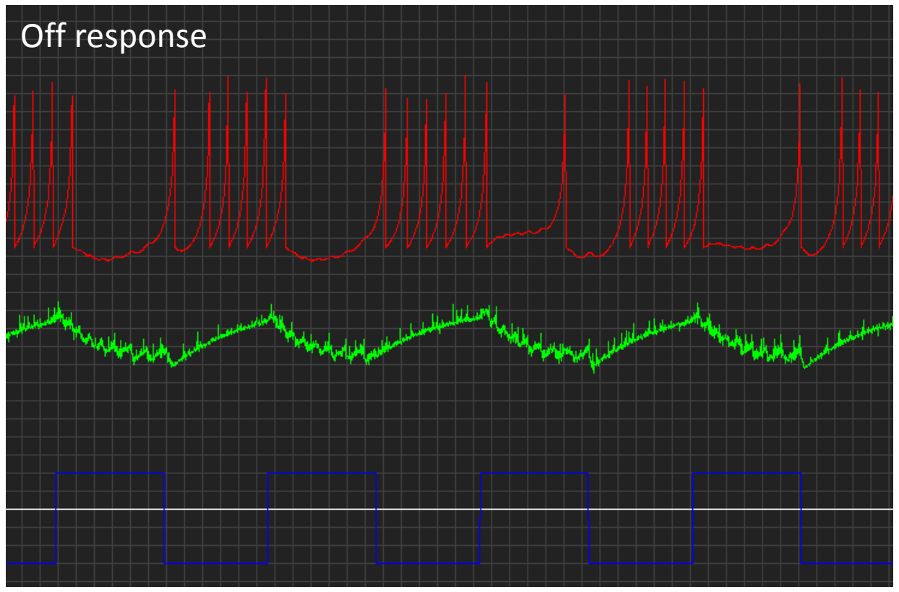
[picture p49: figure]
Off response

This is not a very “good” Off cell. It is a bad Off cell. Sometimes it spikes during the light, and more problematically, the timing of the 1st spike after the light switches off is very variable. This is because now we are not using the presence of an excitatory drive, but rather the absence of an inhibitory drive as signal to generate spikes. Using this setup, you will find it very difficult indeed to tune the off cell to become more transient. The problem is that the synaptic current of the inhibition is slow to decay so after the stimulus switches off the inhibition will take a while to settle back down to zero. This results in a slow upwards trend of the membrane voltage which, as we saw in the beginning, is a very ineffective way to trigger spikes. So, to make it a “better” Off cell, we would need to implement something that makes the membrane potential increase more rapidly after the inhibition turns off. One way to achieve this would be the implementation of a “rebound spike, while another would be the use of a graded (non-spiking) network feeding into Spikeling (as we saw before, membrane voltage is much better at tracking fast inputs below spike-threshold). While Spikeling could principally be programmed to mimic either or both of these possibilities, we will not be covering them here.

Task 21. Using what you have learnt (and two Spikelings), can you build a “delayed ON neuron”? This is a neuron that responds with spike(s) after the onset of a stimulus, but with a delay?

One way of implementing this delayed ON cell would be to use an excitatory synapse that requires more than one presynaptic spike to trigger a postsynaptic spike as shown below. Note the two separate small depolarising current that precede each other by ~100 ms – these come from the presynaptic neuron responding to the light with 2 spikes in close succession. The second incoming spike takes the postsynaptic neuron past threshold.

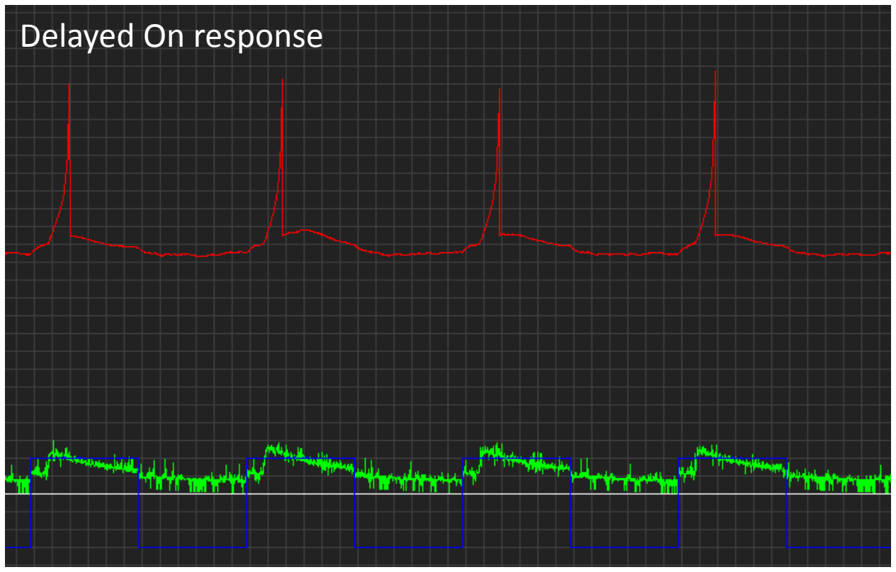
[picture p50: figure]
Delayed On response

Task 22 (final!):

Using the delayed ON neuron circuit, plus an additional non-delayed ON transient neuron, can you build an elementary motion detector? (Hint: This will probably require

### 3 neurons!)

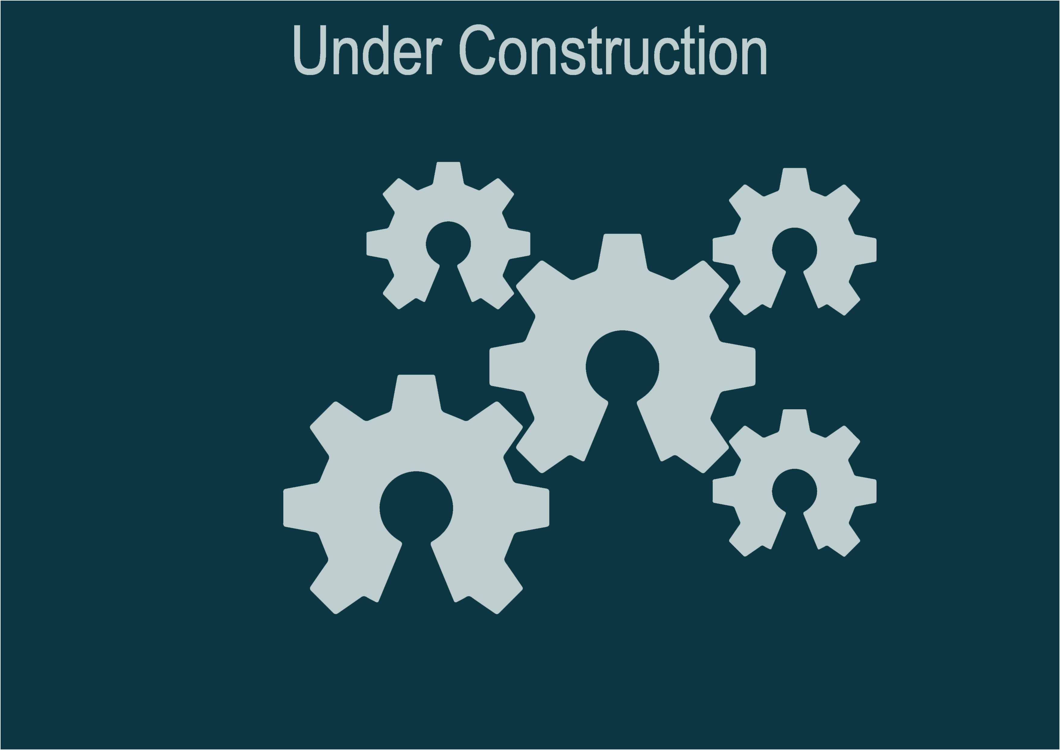
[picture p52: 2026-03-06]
Software/GUI - PyQt6-PySide6/resources/under_construction.png

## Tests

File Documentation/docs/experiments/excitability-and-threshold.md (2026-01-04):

# **Excitability and threshold**

This experiment teaches the core electrophysiology idea of **excitability**: a neuron can switch abruptly from **silent** to **spiking** when input drive crosses a threshold-like boundary.

In Spikeling, you will reproduce this using a current-clamp style workflow:

- control input drive (DC injection, steps, stimulus strength)
- observe **Vm** and **spikes**
- quantify the transition point and how it depends on neuron mode, noise, and stimulus waveform

If you need background first, see: **[Concepts → Threshold and excitability](../user-guide/concepts.md#threshold-and-excitability-why-spiking-starts)**.

---

## **Learning goals**

By the end of this experiment, students should be able to:

- define excitability in terms of **input–output transformation**
- locate an approximate **threshold** for spiking under current clamp
- explain why threshold can be **state dependent** (history and adaptation)
- predict how **noise** alters threshold and spike probability
- compare excitability across different **neuron modes**

---

## **What you need**

- Spikeling hardware (or **Emulator mode**)
- Spikeling GUI
- Optional: second unit for synaptic threshold comparisons

Recommended signals to display:

- **Vm**
- **Total input current** (Itot / Input Current, if available)
- **Stimulus** (if using stimulus protocols)

---

## **Practical notes**

- Start with **small** currents/stimulus strengths.
- Keep **noise off** for the first pass (you will add it later).

---

## **Part A — Threshold with direct DC injection (fastest demonstration)**

**Concept:** in current clamp, the simplest protocol is “hold a constant injected current and observe Vm”.

### Steps (hardware)
1. Set the **current injection potentiometer** to the **centre detent** (0 current).
2. Confirm Vm shows a stable baseline.
3. Turn the potentiometer **slowly right** (depolarising) until spikes begin.
4. Turn slightly back left until spiking stops.
5. Repeat once to confirm reproducibility.

### Steps (emulator)
1. Start emulator and open **Neuron Parameters**.
2. Increase **Patch clamp injected current** slowly until spikes begin.
3. Reduce slightly until spiking stops.
4. Repeat once.

### Record / report
- the approximate injection level where spikes first appear (“threshold injection”)
- Vm baseline and Vm just below threshold
- whether the transition is sharp or gradual

!!! tip "Teaching tip"
    Ask students to predict before turning the knob: *“What should Vm do as I increase depolarising current? When do spikes appear?”*

---

## **Part B — Threshold with a step protocol (more measurable)**

**Concept:** threshold depends on timing; a step stimulus gives you a clean “before/after” window.

### Setup
- Use the GUI **Steps** stimulus routed to **Current**.
- Choose a simple baseline → step → baseline waveform.

### Steps
1. Ensure injected DC is near 0 (or at a fixed small bias).
2. Start with a low step strength (no spikes).
3. Increase step strength in small increments until spikes occur during the step.
4. Run each amplitude 2–3 times.

### Record / measure
- minimal step amplitude that evokes spikes
- spike latency (time from step onset to first spike)
- spike count during the step

### Expected observations
- below threshold: Vm depolarises but no spikes
- at threshold: occasional spikes (often variable)
- above threshold: reliable spiking

---

## **Part C — Threshold is not always a fixed number (state dependence)**

In many neuron models (and biological neurons), the effective threshold depends on the neuron’s state and recent history.

### Demonstration 1: adaptation changes threshold-like behaviour
1. Drive the neuron into sustained spiking for a few seconds.
2. Return to a near-threshold condition.
3. Repeat the same step stimulus as in Part B.

**Observation:** the neuron may require a larger step (or spikes may become less reliable) after recent spiking.

### Demonstration 2: bias current shifts threshold
1. Set a small constant depolarising bias.
2. Re-run the step series.

**Observation:** threshold step amplitude decreases as baseline Vm is closer to spiking.

---

## **Part D — Noise makes threshold probabilistic**

**Concept:** near threshold, noise can trigger spikes even when the mean input is below the deterministic threshold.

### Steps
1. Set injected current so the neuron is **just below threshold** (no spikes).
2. Increase **Noise** gradually.
3. Observe when intermittent spikes appear.
4. Increase noise further to see spike probability/rate rise.

### Measure (simple)
- spike rate vs noise level
- time to first spike after noise is increased (optional)

### Interpretation
- threshold becomes a **probability boundary**, not a single line
- spikes appear via **fluctuation-driven threshold crossings**

---

## **Part E — Compare excitability across neuron modes**

**Concept:** neuron modes differ in intrinsic dynamics; the same input can produce different outputs.

### Steps
1. Choose two or three modes (e.g., regular spiking-like, fast spiking-like, bursting-like).
2. For each mode:
   - find threshold with DC injection (Part A), or
   - find minimal step amplitude that evokes spiking (Part B)
3. Compare:
   - threshold injection/step
   - firing rate above threshold
   - adaptation strength

### Report
A simple table works well:

| Mode | Threshold (DC or step) | Firing rate above threshold | Adaptation (qualitative) |
|---|---:|---:|---|
| Mode A |  |  |  |
| Mode B |  |  |  |
| Mode C |  |  |  |

---

## **Discussion prompts (useful for lab reports)**

- Why might “threshold” depend on recent spiking?
- How does adding noise change the meaning of threshold?
- What does it mean for a neuron to be “more excitable”?
- If two modes have the same threshold, can their firing patterns still differ?

---

## **Extensions (optional)**

- **Strength–duration curve:** vary step duration as well as amplitude.
- **Spike-triggered averages:** align Vm or current around spikes.
- **Synaptic threshold:** use an excitatory synapse input as the drive and ask how much presynaptic spiking is needed to recruit postsynaptic spikes.

---

## **What to read next**

- Pattern diversity: [Adaptation and firing patterns](adaptation-and-firing-patterns.md)
- Synaptic drive: [Synapses and inputs](synapses-and-inputs.md)
- Two-unit coupling: [Network with two units](network-two-units.md)
- Data pipeline: [Recording and export](../user-guide/recording-and-export.md)

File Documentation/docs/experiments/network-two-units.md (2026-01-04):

# **Network with two units**

This experiment builds a minimal spiking network using **two Spikeling units** (or a two-neuron setup in **Emulator mode**). You will create a connection from one unit’s **axon output** to the other unit’s **synapse input**, then explore how coupling sign, strength, and presynaptic firing pattern shape the postsynaptic output.

The point is to teach the simplest network truth in neuroscience:

> Neurons influence each other through spikes, and synapses determine whether those spikes drive or suppress activity.

Background reading:
- [Concepts → Synapses and networks](../user-guide/concepts.md#synapses-and-networks-two-synaptic-inputs)
- [Synapses and inputs](synapses-and-inputs.md)

---

## **Learning goals**

By the end of this experiment, students should be able to:

- wire a two-unit network (axon → synapse) safely and consistently
- demonstrate **excitatory** vs **inhibitory** coupling
- show how presynaptic firing rate affects postsynaptic Vm/spiking (temporal summation)
- create basic motifs: feedforward excitation, feedforward inhibition, and E/I balance (optional)
- measure a simple “network transfer function” (presynaptic rate → postsynaptic rate)

---

## **What you need**

### Hardware route
- **Two Spikeling units** (Unit A presynaptic, Unit B postsynaptic)
- TRS cable for: **Axon output (A) → Synapse input (B)**
- Spikeling GUI

### Emulator route
- Emulator mode with **Auxiliary Neuron 1**
- Optional: Auxiliary Neuron 2 (for E/I balance motifs)

Recommended signals to display (postsynaptic):
- **Vm**
- **Synapse input current** (Synapse 1 / Synapse 2, if available)
- Optional: **Total input current (Itot)**

---

## **Part A — Build the connection**

### Hardware wiring
1. Power and connect both units to the GUI as appropriate for your setup.
2. Patch the TRS cable:
   - **Unit A Axon output → Unit B Synapse input 1**

!!! tip "Cable sanity check"
    If the connection behaves oddly, confirm you have not swapped stimulus and axon ports. Use your labelled cables and the mapping in [Controls and I/O](../user-guide/controls-and-io.md).

### Emulator wiring
1. Start emulator.
2. Configure the main neuron as postsynaptic.
3. Open **Auxiliary Neuron 1**.
4. Enable coupling using **Synapse main neuron**.

---

## **Part B — Establish stable presynaptic spiking (Unit A)**

1. Choose a neuron mode that produces reliable tonic spiking.
2. Use injected current (hardware current injection pot / patch clamp slider) to set a steady spike train.
3. Keep noise off for the first pass.

**Goal:** a stable presynaptic spike train makes synaptic effects easier to interpret.

---

## **Part C — Excitatory coupling (positive synapse gain)**

### Setup (Unit B)
1. Set Unit B to a stable baseline below threshold (silent).
2. Set **Synapse 1 gain** to a small **positive** value.

### Sweep
- Increase synapse gain until you observe:
  - clear depolarising postsynaptic responses, and then
  - postsynaptic spiking (if strong enough)

### What to look for
- postsynaptic Vm deflections time-locked to presynaptic spiking
- summation when presynaptic rate increases
- recruitment into spiking when net drive crosses threshold

---

## **Part D — Inhibitory coupling (negative synapse gain)**

### Setup
1. Keep the same presynaptic spike train.
2. Set **Synapse 1 gain** to a **negative** value.

### What to look for
- postsynaptic Vm becomes more hyperpolarised or less excitable
- spiking is delayed, reduced, or abolished
- inhibition can create **spike skipping** if the postsynaptic neuron is already spiking

---

## **Part E — Network transfer function: presynaptic rate → postsynaptic rate**

This is a clean quantitative network measurement.

### Steps
1. Fix synapse sign and gain (e.g., moderate excitatory).
2. Run several presynaptic firing rates by changing Unit A injected current:
   - low rate
   - medium rate
   - high rate
3. For each presynaptic rate, record 10–20 seconds and measure:
   - presynaptic firing rate (Hz)
   - postsynaptic firing rate (Hz)

### Expected observations
- excitatory coupling: postsynaptic rate increases with presynaptic rate (often non-linear)
- inhibitory coupling: postsynaptic rate decreases as presynaptic rate increases

---

## **Part F — Timing and coincidence (optional)**

If you have **three units** (or emulator with two auxiliaries), you can show coincidence detection:

- Unit A → Synapse 1 on Unit B (excitatory)
- Unit C → Synapse 2 on Unit B (excitatory)

Adjust presynaptic timing so spikes sometimes coincide.

**Observation:** coincident input can recruit a postsynaptic spike when either input alone cannot.

---

## **Part G — E/I balance (optional but powerful)**

Use two inputs with opposite sign:

- Synapse 1: excitatory (positive)
- Synapse 2: inhibitory (negative)

Explore how inhibition shapes excitation:

- vetoing spikes
- delaying spikes
- sharpening spike timing
- controlling output rate without changing mean input current directly

---

## **Measurements (choose one, depending on level)**

Simple, robust metrics:

- **Postsynaptic firing rate** vs synapse gain
- **Postsynaptic spike probability** per presynaptic burst
- **Latency** between presynaptic spike and postsynaptic spike
- **Summation index**: peak Vm deflection after a burst / after a single spike

---

## **Common issues**

- **No postsynaptic effect**
  - presynaptic unit may not be spiking
  - synapse gain may be near zero
  - wrong ports/cable routing

- **Postsynaptic neuron saturates**
  - synapse gain too strong
  - postsynaptic bias current too depolarising
  - reduce gain and re-centre the postsynaptic baseline

---

## **Discussion prompts**

- Why does synaptic decay enable temporal integration?
- How can inhibition control spike timing without necessarily changing mean Vm much?
- Why is the network transfer function non-linear near threshold?
- What would happen if both neurons were adapting strongly?

---

## **What to read next**

- Detailed synapse mechanisms: [Synapses and inputs](synapses-and-inputs.md)
- Intrinsic dynamics: [Adaptation and firing patterns](adaptation-and-firing-patterns.md)
- Threshold background: [Excitability and threshold](excitability-and-threshold.md)
- Record and analyse: [Recording and export](../user-guide/recording-and-export.md)

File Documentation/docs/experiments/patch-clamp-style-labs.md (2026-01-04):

# **Patch-clamp-style labs**

This page provides a set of **patch-clamp-inspired laboratory activities** designed for Spikeling. The goal is to teach the *logic* of electrophysiology (current clamp thinking, excitability, adaptation, synaptic integration) using a reproducible hardware+GUI workflow.

These labs are written for university-level teaching:

- quick to run (typically 10–30 minutes per activity)
- easy to scaffold (intro → prediction → run → interpret)
- compatible with **hardware** and **emulator mode**

If you want a minimal setup sequence first, see: **[Quickstart → First experiment](../quickstart/first-experiment.md)**.

---

## **What students should practise**

Across the labs, students will practise:

- identifying baseline Vm, threshold, and spiking regimes
- predicting responses before changing a parameter (“hypothesis-first”)
- designing simple protocols to test excitability and adaptation
- measuring outputs (spike count, firing rate, latency, jitter)
- connecting stimulation choice (waveform, frequency, amplitude) to interpretation
- recording and exporting data for analysis (CSV → Python)

---

## **General workflow (applies to all labs)**

1. **Start from a known baseline**
   - current injection at **0** (centre detent / patch clamp neutral)
   - stimulus off
   - noise off (unless the lab is about noise)

2. **Choose one neuron mode and keep it fixed**
   - The neuron mode controls intrinsic dynamics.
   - Changing mode mid-lab is useful, but only after students have drawn conclusions with one stable mode.

3. **Apply an input**
   - DC injection (Patch clamp / current injection potentiometer), or
   - programmed stimulus from the GUI (Steps, sine/triangle, chirp, noise), or
   - synaptic input from another unit / emulator auxiliary neuron.

4. **Observe Vm and spikes**
   - Vm tells the state; spikes are discrete events.

5. **Record**
   - Record a short segment (10–30 s) once the behaviour is stable.
   - Export to CSV.

6. **Measure one thing**
   - spike count, firing rate, latency, adaptation index, etc.

7. **Interpret**
   - connect “what I changed” to “what I saw”.

!!! tip "Teaching rhythm"
    The fastest way to build intuition is: **predict → test → explain**.
    Make students state the expected change *before* moving a slider.

---

## **Lab 0 — Warm-up: finding threshold (current clamp intuition)**

**Question:** How much injected current is needed to make the neuron spike?

**Inputs:** DC current injection (Patch clamp / current injection potentiometer)

### Steps
1. Ensure stimulus and noise are off.
2. Increase injected current until Vm begins to spike.
3. Reduce slightly until spiking stops again.
4. Repeat once to confirm reproducibility.

### What to record / measure
- threshold current (approximate)
- Vm just below threshold vs just above threshold
- spike latency (time from start of injection to first spike)

### Expected observations
- Below threshold: Vm shifts but no spikes.
- Near threshold: small differences can change outcome.
- Above threshold: sustained spiking.

---

## **Lab 1 — Step protocol: excitability and firing rate**

**Question:** How does firing rate depend on input amplitude?

**Inputs:** GUI **Steps** stimulus routed as **Current** (or manual DC steps)

### Steps
1. Route stimulus to **Current**.
2. Choose a simple step: baseline → step → baseline (e.g., 1–2 s step).
3. Run multiple step amplitudes (increasing strength).
4. Keep neuron mode fixed.

### What to measure
- spike count during the step
- mean firing rate during the step (spikes / second)

### Expected observations
- increased step amplitude increases firing rate
- spiking may show adaptation (rate decreases over time during the step)

---

## **Lab 2 — Spike-frequency adaptation (early vs late rate)**

**Question:** Does firing rate remain constant under constant drive?

**Inputs:** constant DC injection or a long step

### Steps
1. Apply a sustained depolarising current that produces stable spiking.
2. Keep it constant for 5–10 seconds.
3. Record and export.

### What to measure
- firing rate in an early window (e.g., first 1–2 s)
- firing rate in a late window (e.g., last 1–2 s)
- adaptation index: (early − late) / early

### Expected observations
- rate typically decreases over time in adapting modes
- some modes adapt weakly or not at all (fast-spiking-like behaviour)

---

## **Lab 3 — Subthreshold dynamics and resonance (optional extension)**

**Question:** Does the neuron respond preferentially to certain frequencies?

**Inputs:** sine wave or chirp stimulus at subthreshold amplitude

### Steps
1. Set injected current so Vm is below threshold (no spikes).
2. Apply a small sine wave (or chirp) stimulus.
3. Observe the amplitude of Vm oscillations as frequency changes.

### What to look for
- Vm response may grow at certain frequency ranges (resonance-like behaviour)
- responses may depend strongly on neuron mode

!!! note
    This is an advanced conceptual lab. If short on time, run it as a demonstration.

---

## **Lab 4 — Noise and stochastic spiking**

**Question:** Can noise alone trigger spikes near threshold?

**Inputs:** Noise + near-threshold bias current

### Steps
1. Bias Vm just below threshold using injected current.
2. Increase Noise gradually.
3. Observe when intermittent spikes appear.

### What to measure
- spike rate as a function of noise level
- spike-time jitter (variability)

### Expected observations
- spikes appear probabilistically at sufficient noise levels
- rate increases with noise amplitude
- spike timing becomes less precise

---

## **Lab 5 — Synaptic input as a current source (two-unit coupling)**

**Question:** How do excitatory vs inhibitory synapses affect postsynaptic spiking?

**Inputs:** presynaptic spiking from another unit (or emulator auxiliary neuron)

### Steps (hardware)
1. Connect: **Axon output (Unit A) → Synapse input (Unit B)**.
2. Make Unit A spike reliably (inject current).
3. Set synapse gain on Unit B:
   - positive (excitatory) then negative (inhibitory)
4. Observe changes in Unit B Vm and spiking.

### Steps (emulator)
1. Configure **Auxiliary Neuron 1** to spike.
2. Enable **Synapse main neuron**.
3. Set synapse sign/gain and observe the main neuron output.

### What to measure
- probability of postsynaptic spikes per presynaptic spike train
- change in baseline Vm under sustained synaptic drive
- suppression effects under inhibition

---

## **Lab 6 — “Design your own protocol” (capstone mini-lab)**

**Question:** Can students propose and test a hypothesis about excitability?

### Example hypotheses
- “This neuron responds more strongly to low frequencies than high frequencies.”
- “Inhibition can prevent spiking even when DC current is above threshold.”
- “Noise increases spike-time variability but not mean Vm.”

### Requirements (student checklist)
- write a one-sentence hypothesis
- choose a stimulus waveform that tests it (Steps, sine, chirp, noise)
- record one dataset
- compute one metric
- interpret results in 3–5 sentences

---

## **Practical notes (common issues)**

!!! tip "Start simple"
    If results are confusing, disable everything except one input pathway:
    **no noise, no light, no synapses** — then add one pathway at a time.

- If traces clip or look unstable, reduce stimulus strength and confirm grounding/cables.
- If the device stops streaming, press **Reset** and re-connect in the GUI.
- For teaching at scale, use emulator mode first to standardise expectations.

---

## **What to read next**

- Structured activities by topic:
  - [Excitability and threshold](excitability-and-threshold.md)
  - [Adaptation and firing patterns](adaptation-and-firing-patterns.md)
  - [Synapses and inputs](synapses-and-inputs.md)
  - [Network with two units](network-two-units.md)

- How to record and analyse:
  - [Recording and export](../user-guide/recording-and-export.md)
  - [Python quickstart](../data-analysis/python-quickstart.md)

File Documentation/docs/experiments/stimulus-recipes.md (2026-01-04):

# **Stimulus recipes**

This page is a practical cookbook of stimulus patterns you can run with Spikeling. Each recipe states:

- **what to select in the GUI**
- **what to set**
- **what it teaches**
- **what to look for in Vm and spikes**

Spikeling supports two main stimulus pathways:

- **Current stimulus**: inject the waveform directly as input drive (current clamp logic)
- **Light stimulus**: drive an LED (stimulus output → LED cable) and stimulate the photodiode pathway

For background on stimulus modes, see: [Concepts → Stimulus protocols](../user-guide/concepts.md#stimulus-protocols-what-is-built-in-vs-what-the-gui-adds).

---

## **Before you start (recommended setup)**

- Pick one **neuron mode** and keep it fixed during a recipe.
- Start with:
  - injected current = 0 (centre detent / patch clamp neutral)
  - noise = off (unless the recipe is about noise)
  - synapses = off (unless the recipe is about synapses)
- Display:
  - **Vm**
  - **Stimulus** (or the current trace if you route stimulus as current)
  - Optional: **Total input current (Itot)**

!!! tip "Teaching rhythm"
    For each recipe: make students predict the response, then run it, then explain what changed.

---

## **Recipe 1 — Single step (classic current clamp protocol)**

**Use:** threshold finding, adaptation, F–I curves  
**GUI mode:** `Steps`  
**Route:** `Current`

### Settings (suggested)
- Baseline: 1 s
- Step duration: 2–5 s
- Return to baseline: 1 s
- Step amplitude: start small and increase

### What to look for
- Vm depolarisation/hyperpolarisation during the step
- spikes appear once the step crosses threshold
- adaptation: spike rate often slows over time during a long step

---

## **Recipe 2 — Step family (build an F–I curve)**

**Use:** excitability quantification  
**GUI mode:** `Steps`  
**Route:** `Current`

### Settings
Run a sequence of step amplitudes (e.g., 6–10 levels), keeping duration fixed.

### Measure
- spike count or firing rate during each step
- plot firing rate vs step amplitude

---

## **Recipe 3 — Pulse train (frequency vs strength)**

**Use:** recruitment, frequency following, reliability  
**GUI mode:** pulse/square train (or square-like train via your GUI controls)  
**Route:** `Current` (or `Light` for flicker teaching)

### Settings
- Set pulse strength moderate
- Sweep frequency (e.g., low → high)
- Then fix frequency and sweep strength

### What to look for
- some frequencies produce reliable time-locked spiking
- at high frequencies, Vm may integrate or spikes may fail depending on mode

---

## **Recipe 4 — Sine wave (subthreshold resonance)**

**Use:** membrane filtering, resonance intuition  
**GUI mode:** `Sine`  
**Route:** `Current`

### Settings
- Use small amplitude to keep Vm subthreshold
- Sweep frequency manually or run several fixed frequencies

### What to look for
- Vm oscillation amplitude depends on frequency and neuron mode
- some modes show stronger response in certain frequency bands

!!! note
    This is best as a demonstration unless students already know resonance/impedance concepts.

---

## **Recipe 5 — Triangle wave (rate-of-change and threshold crossing)**

**Use:** compare rising vs falling phases; “when does threshold get crossed?”  
**GUI mode:** `Triangle`  
**Route:** `Current`

### Settings
- Moderate amplitude
- Low–moderate frequency

### What to look for
- spikes often cluster near the peaks (depending on mode)
- threshold crossing can differ on rising vs falling ramps

---

## **Recipe 6 — Chirp / ZAP sweep (frequency probing)**

**Use:** resonance, frequency preference, dynamic response  
**GUI mode:** `Chirp` (linear or exponential; amplitude increase variants if available)  
**Route:** `Current`

### Settings
- Keep amplitude subthreshold at first
- Sweep over a wide band (e.g., low → high)

### What to look for
- Vm response changes across the sweep
- some modes show “preferred” frequency ranges with larger Vm deflections

---

## **Recipe 7 — Noise stimulus (variability under controlled conditions)**

**Use:** stochastic spiking, jitter, threshold probability  
**GUI mode:** `Noise`  
**Route:** `Current`

### Settings
- Set a small depolarising bias current so Vm is near threshold
- Increase noise amplitude gradually

### What to look for
- intermittent spikes appear without changing mean input
- spike timing becomes variable
- rate increases with noise amplitude

---

## **Recipe 8 — On-board square stimulus (fast classroom demo)**

**Use:** immediate hands-on demonstration  
**Source:** on-board square stimulus generator  
**Controls:** frequency + strength knobs (board)

### Workflow
1. Keep current injection at zero initially.
2. Increase stimulus strength until Vm deflections are clear.
3. Increase frequency and observe changes in spiking reliability.

### What to look for
- easy “knob-to-trace” intuition
- quick illustration of strength vs frequency effects

---

## **Recipe 9 — Light flicker (sensory-style stimulation)**

**Use:** visual sensory analogue; polarity inversion with Photo-gain  
**Route:** `Light`

### Two common setups
- **Controlled LED**: stimulus output → LED cable → photodiode
- **External LED source**: any modulated light aimed at the photodiode

### Settings
- Start with modest **Photo-gain**
- Use square pulses or a pulse train to deliver flicker
- Flip Photo-gain sign to show excitatory vs inhibitory sensory drive

### What to look for
- same light can depolarise or hyperpolarise depending on gain sign
- photoreceptor dynamics (decay/recovery) shape response to flicker

---

## **Recipe 10 — Synaptic drive bursts (postsynaptic recruitment)**

**Use:** integration, coincidence, E/I balance  
**Source:** presynaptic unit spikes (or emulator auxiliary neuron)

### Workflow
1. Create presynaptic spiking bursts (increase presynaptic drive briefly).
2. Set postsynaptic neuron below threshold.
3. Increase synapse gain until bursts recruit postsynaptic spikes.

### What to look for
- burst summation is more effective than isolated spikes
- inhibition can veto recruitment

---

## **Recipe 11 — “Design your own stimulus” (student capstone)**

**Use:** experimental design thinking  
**Goal:** students build a stimulus to test a hypothesis.

Example hypotheses:
- “This mode adapts strongly, so a long step will slow firing.”
- “Noise increases spike-time jitter but does not strongly change mean Vm.”
- “This neuron responds differently to slow vs fast oscillatory inputs.”

Student checklist:
- write the hypothesis
- choose waveform type
- choose amplitude and timing
- record one dataset
- compute one metric
- interpret results

---

## **Practical tips**

- If you are confused, disable everything except **one** input pathwa

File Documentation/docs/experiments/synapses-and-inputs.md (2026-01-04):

# **Synapses and inputs**

This experiment introduces synaptic integration using Spikeling. You will connect a presynaptic unit to a postsynaptic unit (or emulate the same setup in software) and observe how spikes from one neuron produce input currents and Vm changes in another neuron.

Spikeling simplifies synaptic physiology into a teaching-friendly model:

- presynaptic **spikes** arrive as discrete events
- each spike generates an **exponentially decaying synaptic current**
- synapse gain can be **positive** (excitatory) or **negative** (inhibitory)

Background reading: [Concepts → Synapses and networks](../user-guide/concepts.md#synapses-and-networks-two-synaptic-inputs).

---

## **Learning goals**

By the end of this experiment, students should be able to:

- explain how presynaptic spikes create postsynaptic input currents
- distinguish **excitatory** vs **inhibitory** synapses by sign and effect on Vm
- demonstrate temporal summation (integration) of repeated synaptic events
- predict how synapse gain and decay shape postsynaptic spiking
- build simple network motifs (feedforward excitation, inhibition, E/I balance)

---

## **What you need**

### Hardware route
- **Two Spikeling units** (Unit A presynaptic, Unit B postsynaptic)
- A **TRS cable** to connect:
  - **Axon output (Unit A) → Synapse input (Unit B)**
- Spikeling GUI for monitoring and recording

### Emulator route
- One computer running the GUI
- Emulator mode with **Auxiliary Neuron 1** (and optionally Auxiliary Neuron 2)

Recommended signals to display on the postsynaptic unit:
- **Vm**
- **Synapse 1 input current** / **Synapse 2 input current** (if available)
- **Total input current (Itot)** (optional but very helpful)

---

## **Part A — Wiring (hardware)**

1. Connect Unit A and Unit B to the GUI (or select one to monitor at a time depending on your setup).
2. Patch a TRS cable:
   - **Axon output (Unit A) → Synapse input 1 (Unit B)**

!!! note "Ground reference"
    If you see confusing behaviour, confirm that both units share a consistent ground reference through the cable conventions used in your setup (see: [Controls and I/O](../user-guide/controls-and-io.md)).

---

## **Part B — Create a presynaptic spike train**

### Presynaptic (Unit A)
1. Choose a neuron mode that spikes reliably.
2. Use injected current (hardware knob or Patch clamp slider) to produce steady spiking.
3. Optionally add a low level of noise for realism (but keep it minimal at first).

### Target
A stable, regular presynaptic spike train makes postsynaptic effects easier to interpret.

---

## **Part C — Excitatory synapse (positive gain)**

### Postsynaptic (Unit B)
1. Ensure Unit B is initially **below threshold** (silent) using its current injection / patch clamp.
2. Set **Synapse 1 gain** to a **positive** value.
3. Observe Vm on Unit B.

### What to look for
- Each presynaptic spike produces a **brief depolarising drive**
- With repeated spikes, depolarisations can **summate**
- If strong enough, the synaptic drive can recruit postsynaptic spiking

!!! tip "Teaching tip"
    Start with Unit B just below threshold. Then increase synapse gain slightly until synaptic input reliably triggers spikes. This makes “synapses can drive firing” very intuitive.

---

## **Part D — Inhibitory synapse (negative gain)**

1. Keep the presynaptic spike train the same.
2. Set **Synapse 1 gain** to a **negative** value.
3. Observe postsynaptic Vm and spiking.

### What to look for
- Each presynaptic spike produces a **hyperpolarising** effect or a reduction in spiking probability
- Inhibition can:
  - suppress spiking entirely
  - delay spikes
  - create spike skipping (missed spikes)

---

## **Part E — Synaptic summation and time constants (decay)**

**Concept:** synapses are filters in time. If the synaptic current decays slowly, inputs integrate more strongly.

### Steps
1. Set Unit B below threshold.
2. Keep synapse gain fixed (moderate excitatory).
3. Increase presynaptic firing rate (increase injection in Unit A).
4. Observe whether postsynaptic depolarisation builds up.

### Expected observations
- At low presynaptic rate: isolated postsynaptic responses
- At higher presynaptic rate: responses overlap and **summate**
- Summation can push Vm over threshold and trigger postsynaptic spikes

If your build exposes synapse decay parameters in the GUI:
- **faster decay** → sharper, briefer postsynaptic effects (less summation)
- **slower decay** → more integration (more summation)

---

## **Part F — Two synapses: coincidence and competition**

Spikeling supports **two synaptic inputs**, which enables simple network motifs.

### Motif 1: coincidence detection (two excitatory synapses)
1. Connect Unit A → Synapse 1 on Unit B.
2. Connect a second presynaptic unit (Unit C) → Synapse 2 on Unit B (or use emulator Auxiliary Neuron 2).
3. Set both synapses excitatory at moderate gain.
4. Adjust presynaptic timing/rates so that spikes sometimes coincide.

**Observation:** coincident excitatory input can trigger postsynaptic spikes when either input alone cannot.

### Motif 2: E/I balance (excitation + inhibition)
1. Set Synapse 1 as excitatory (positive gain).
2. Set Synapse 2 as inhibitory (negative gain).
3. Compare postsynaptic output under different E/I ratios.

**Observation:** inhibition can veto or shape excitation, controlling spike timing and probability.

---

## **Emulator version (no hardware needed)**

In emulator mode, reproduce the same logic:

1. Start emulator and configure the **main neuron** (postsynaptic).
2. Open **Auxiliary Neuron 1** and drive it to spike (Patch clamp).
3. Enable coupling (toggle **Synapse main neuron**).
4. Use Synapse gain (1 or 2) to set:
   - excitatory (positive)
   - inhibitory (negative)
5. Repeat with a second auxiliary neuron if available to demonstrate E/I balance.

---

## **What to measure (simple, robust metrics)**

Choose one metric depending on your course level:

- **Postsynaptic spike probability** vs synapse gain
- **Postsynaptic firing rate** vs presynaptic firing rate
- **Latency** from presynaptic spike to postsynaptic spike (when recruited)
- **Summation index**: Vm deflection after a burst vs a single presynaptic spike

---

## **Discussion prompts**

- Why do synapses need a time course (why not instantaneous)?
- What changes when synapse sign is inverted?
- How does presynaptic firing rate interact with synaptic decay to control integration?
- In what situations might inhibition be more important than excitation?

---

## **What to read next**

- Two-unit experiments and motifs: [Network with two units](network-two-units.md)
- Threshold and adaptation background:
  - [Excitability and threshold](excitability-and-threshold.md)
  - [Adaptation and firing patterns](adaptation-and-firing-patterns.md)
- Recording and analysis pipeline: [Recording and export](../user-guide/recording-and-export.md)

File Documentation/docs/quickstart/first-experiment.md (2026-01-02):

# **First experiment**

This page walks you through a minimal “first success” experiment: connect to Spikeling, stream data, apply a simple stimulus, and record a short CSV. The goal is to confirm your setup works end-to-end before attempting more advanced protocols.

## **Before you start**

Complete these first:

- **Hardware is connected and the port is visible**: see [Hardware setup](hardware-setup.md)
- **GUI is installed and launches**: see [Install the GUI](install-gui.md)
- (Optional) Firmware is up to date: see [Flash firmware](flash-firmware.md)

!!! warning "Close other serial tools"
    If Arduino Serial Monitor or another terminal is open, the GUI may not be able to connect to the port.

---

## **Step 1 — Connect to the device**

1. Plug the board in and confirm it appears as a serial/COM port.
2. Open the Spikeling GUI.
3. Select the correct **Port**:
   - v2.x (CP210x): typically appears as a CP210x/SLAB serial port (COMx on Windows)
   - v3.x (USB CDC): typically appears as a USB serial device (COMx on Windows)
4. Click **Connect** (or the equivalent connect action in your GUI).

### **Success criteria**

- The GUI shows **Connected** (or an equivalent status)
- a little light gimmick is displayed on the board
- Live plots begin to update (even if flat/no stimulus yet)

If you cannot connect, go to [Troubleshooting](troubleshooting.md).

---

## **Step 2 — Verify live streaming (baseline)**

Before applying any stimulus, check that the streaming pipeline is alive.

1. Confirm the main traces update at a steady rate.
2. Confirm you can see at least one channel that changes over time (even small noise is fine).

### **If everything is flat**

A flat baseline can still be normal depending on the channel shown and defaults. The key is:
- the plot is updating in real time, and
- the connection is stable (no repeated disconnects).

---

## **Step 3 — Use the current injection potentiometer (first hands-on control)**

Before running any stimulus protocol, use the **current input potentiometer** on the board to directly inject DC current, like a patch-clamp pipette in current-clamp mode.

On Spikeling, this potentiometer is located in the **bottom-left corner** of the board, on the drawing of the **electrophysiology pipette**. It corresponds to the **direct current input from the pipette**.

### **Center detent behavior (important)**

This is a **center-detent potentiometer**:

- **Center detent** = **0 current** (no DC injection)
- Turn **left** from center = **hyperpolarizing current** (Vm decreases)
- Turn **right** from center = **depolarizing current** (Vm increases)

### **What you are doing conceptually**

By turning this knob you are changing a **constant input current**. This should shift the membrane potential (Vm) and can drive different regimes:

- hyperpolarizing current → **hyperpolarization**
- depolarizing current → **depolarization**
- sufficiently depolarizing current → **spiking**
- sustained spiking → **spike-frequency adaptation** (spikes slow down over time)

### **Procedure**

1. Ensure the GUI is connected and you are viewing the **Vm** trace.
2. Set the potentiometer to the **center detent** (0 current).
   - You should see a stable baseline Vm (with small noise).
3. Turn the potentiometer **slightly left** of center:
   - observe **hyperpolarization** (Vm baseline shifts downward)
4. Return to the **center detent**:
   - Vm should return toward baseline
5. Turn the potentiometer **slightly right** of center:
   - observe **depolarization** (Vm baseline shifts upward)
6. Continue turning **right** until you reach **spiking**:
   - spikes should appear on the Vm trace
7. Hold the knob at a fixed rightward position for several seconds:
   - observe **spike adaptation** (firing rate decreases over time; inter-spike interval increases)

!!! tip "Move slowly and allow settling time"
    Small knob movements can produce large qualitative changes (silent → spiking). Make changes gradually and give the trace time to settle.

### **Success criteria**

You should be able to demonstrate all four regimes, in order:

- **Zero-current baseline** at the center detent
- **Hyperpolarized** Vm (turn left)
- **Depolarized** Vm (turn right)
- **Spiking** and **adaptation** during sustained rightward current

If you cannot reach spiking:
- confirm you are observing the correct channel (Vm)
- confirm the GUI is streaming live data
- verify your board is running the expected firmware/configuration
- see [Troubleshooting](troubleshooting.md)

---

## **Step 4 — Run a simple stimulus protocol**

Once you have confirmed that direct current injection works, you can run a simple stimulus protocol from the GUI (for example a step or pulse train) to observe transient responses superimposed on the baseline set by the current injection knob.

Procedure:

1. Set the current injection potentiometer back to the **center detent** so the baseline is stable.
2. On the experiment box on the board (dashed lines), select square stimulus strength and frequency by modifying the two potentiometer on the right. At first set the stimulus strength to positive (right) values.
3. Plug a cable from **stimulus output** (bottom right corner) to **current input** (bottom left)
4. Run the stimulus and observe how Vm responds.

### **Success criteria**

- Vm shows a reproducible change aligned with the stimulus window
- The response depends on baseline (e.g., near threshold you may trigger spikes)

---
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

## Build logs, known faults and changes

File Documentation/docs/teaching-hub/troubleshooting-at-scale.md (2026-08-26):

# Troubleshooting at scale

This page routes instructors and teaching assistants to the current operational documentation and curriculum validation checks. It does not duplicate device-specific troubleshooting instructions.

## Fast triage route

1. **Confirm the affected scope.** Determine whether the problem affects one station, one board, one computer image or the whole class.
2. **Return to a known baseline.** Run the operational checks in [Quickstart troubleshooting](../quickstart/troubleshooting.md).
3. **Check the relevant workflow.** Use the [hardware setup](../quickstart/hardware-setup.md), [GUI installation](../quickstart/install-gui.md), [controls and I/O](../user-guide/controls-and-io.md), or [recording and export](../user-guide/recording-and-export.md) page as appropriate.
4. **Protect the scientific result.** If timing, parameters, recording metadata or board-to-board behaviour cannot be validated, do not continue to quantitative interpretation.
5. **Record the failure.** Note the hardware, firmware and GUI versions, settings, expected behaviour, observed behaviour and whether the fault follows the board, cable or computer.

## Curriculum-specific stop conditions

Pause or adapt the activity when:

- the EPH-04 timing gateway has not been completed for a time-derived measure;
- an imaging preset's active parameters have not been checked;
- a multi-board activity relies on unmeasured delays;
- an extracellular activity relies on unvalidated timestamps or spectral scales; or
- a required fallback dataset or notebook is referenced by the specification but has not yet been released.

These conditions are documented in [Development status and validation gates](development-status.md).

## Escalation

If the operational guides do not resolve a reproducible problem, search or open an issue in the [Spikeling GitHub repository](https://github.com/OpenSourceNeuro/Spikeling/issues). Include version information and a minimal reproduction; do not include student-identifiable data.

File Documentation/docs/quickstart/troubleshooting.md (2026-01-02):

# **Troubleshooting**

This page helps you quickly diagnose and fix the most common Spikeling setup issues.
Start with the symptom that best matches what you see.

## **Quick triage checklist (do this first)**

- [ ] Use a **known-good USB data cable** (charge-only cables are the #1 cause of failures)
- [ ] Try a different USB port (or a **powered USB hub**)
- [ ] Close anything that can own the serial port (Arduino Serial Monitor, PlatformIO monitor, PuTTY, CoolTerm, etc.)
- [ ] Confirm you selected the **correct port** in the GUI (unplug/plug trick)
- [ ] Confirm your board family:
  - v2.x: mini-USB + CP210x driver
  - v3.x: USB-C + native USB CDC (usually no driver)

---

## **Symptom A — The device does not appear as a serial/COM port**

### **A1) You are using v2.x (mini-USB, CP210x)**

Most likely causes:
- CP210x driver not installed
- bad/charge-only cable
- insufficient USB power

Fix:
1. Install the CP210x driver:
   - https://www.silabs.com/developers/usb-to-uart-bridge-vcp-drivers
2. Unplug/replug the board.
3. Check again:
   - Windows: Device Manager → Ports (COM & LPT) → “Silicon Labs CP210x … (COMx)”
   - macOS: `/dev/tty.SLAB_USBtoUART`
   - Linux: `/dev/ttyUSB0` (or another `ttyUSB*`)

If still missing:
- try another USB cable
- try a powered hub

### **A2) You are using v3.x (USB-C, ESP32-S3 native USB)**

Most likely causes:
- bad/charge-only USB-C cable (very common)
- problematic USB port/hub

Fix:
1. Swap the USB-C cable (use a verified **data** cable).
2. Try a different USB port (or a powered hub).
3. Check again:
   - Windows: Device Manager → Ports (COM & LPT) → “USB Serial Device (COMx)” (name may vary)
   - macOS: `/dev/tty.usbmodem*` or `/dev/cu.usbmodem*`
   - Linux: `/dev/ttyACM0` (or another `ttyACM*`)

---

## **Symptom B — The port exists but the GUI cannot connect**

Most likely causes:
- another application is using the port
- wrong port selected
- intermittent USB cable/power

Fix (in order):
1. Close Arduino Serial Monitor / PlatformIO monitor / any serial terminal.
2. In the GUI, refresh the port list and reconnect.
3. Use the “unplug/plug trick”:
   - unplug the board
   - note the port list
   - plug it back in
   - select the **new** port that appears
4. Swap USB cable and/or use a powered hub.

---

## **Symptom C — The GUI connects, but plots are flat / not updating**

First, distinguish between “flat but updating” and “not updating”.

### **C1) The plot is updating (time moves), but Vm is flat**

This can be normal at baseline. To confirm the system responds:

1. Go to the board’s **current injection potentiometer** (bottom-left, on the pipette graphic).
2. Confirm it is at the **center detent** (0 current).
3. Turn **left** from center → Vm should **hyperpolarize**.
4. Return to center.
5. Turn **right** from center → Vm should **depolarize** and may spike.

If Vm does not respond:
- confirm you are viewing the correct trace (Vm)
- confirm the GUI is in hardware mode (not emulator-only, if applicable)
- consider reflashing firmware (see [Flash firmware](flash-firmware.md))

### **C2) The plot is not updating at all**

Most likely causes:
- streaming is not started/enabled in the GUI
- the GUI is connected but not receiving data
- a performance issue is freezing updates

Fix:
1. Look for a **Start/Stop streaming** control in the GUI and ensure streaming is enabled.
2. Disconnect and reconnect.
3. Reduce load:
   - close other heavy applications
   - try a powered hub
4. If the GUI becomes unresponsive, see “Symptom F — GUI is slow or freezes”.

---

## **Symptom D — I can depolarize/hyperpolarize, but I cannot reach spikes**

Most likely causes:
- knob range not reaching threshold due to configuration/calibration
- you are not observing the correct channel
- firmware mismatch for your board family

Fix:
1. Confirm you are looking at the correct Vm channel.
2. Move slowly to the right (depolarizing direction) and hold for a few seconds.
3. If still no spikes:
   - confirm the firmware you flashed matches your board family (v2.x vs v3.x)
   - reflash firmware with a clean upload (see [Flash firmware](flash-firmware.md))

---

## **Symptom E — Very noisy signal / unstable baseline**

Most likely causes:
- poor grounding between connected devices
- long TRS cables picking up noise
- USB power noise from laptop ports

Fix:
1. Keep TRS cables short, especially for analog (Ring).
2. Confirm a stable ground reference:
   - TRS Sleeve (S) is ground
   - if using multiple devices, ensure grounds are shared intentionally
3. Try a powered USB hub.
4. Move away from strong noise sources (chargers, laptop bricks, fluorescent lamps).

---

## **Symptom F — GUI is slow, freezes, or plots lag**

Most likely causes:
- plotting too much data at high refresh rate
- a slow machine or overloaded CPU
- background tasks interfering

Fix:
1. If the GUI has options for:
   - **decimation**
   - **buffer length**
   - **update rate**
   reduce them.
2. Close other applications.
3. Prefer a wired mouse/keyboard over heavy USB peripherals if using a marginal hub.
4. If you run from source, ensure you installed the pinned requirements versions.

---

## **Symptom G — LED stimulus does not work / photodiode does not respond**

### **G1) LED does not light**

Fix:
1. Verify the LED cable is connected to the correct jack.
2. Check LED polarity and wiring (LEDs are directional).
3. Run a simple on/off light stimulus in the GUI.

### **G2) LED lights, but photodiode trace does not change**

Fix:
1. Position the LED close to the photodiode and stabilize it (tape/mount).
2. Reduce ambient light for a clean signal.
3. Confirm you are viewing the correct photodiode/sensor channel in the GUI.

---

## **Symptom H — Flashing firmware fails**

Most likely causes:
- wrong board selected in Arduino IDE
- port is in use
- board not in download mode

Fix:
1. Close anything using the serial port.
2. Confirm you selected the correct board target:
   - v2.x: ESP32 Dev Module (or equivalent ESP32 target)
   - v3.x: ESP32S3 Dev Module (or equivalent ESP32-S3 target)
3. Try the BOOT/RESET download mode sequence (if available).
4. See the detailed guide: [Flash firmware](flash-firmware.md)

---

## **If you need help (what to include)**

When reporting an issue, include:

- board family: v2.x or v3.x
- OS: Windows/macOS/Linux
- which port name you see (COMx or `/dev/...`)
- GUI version (or commit, if running from source)
- firmware version (if known)
- what you expected vs what happened
- screenshots of:
  - GUI connection panel
  - Device Manager (Windows) or port list (`ls /dev/tty*`) if relevant

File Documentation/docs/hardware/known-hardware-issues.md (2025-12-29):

# Known hardware issues

Track known issues and validated fixes.

## Symptoms → likely causes

TODO

## Workarounds

TODO

## Permanent fixes

TODO

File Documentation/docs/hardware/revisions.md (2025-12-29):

# Revisions

Board revisions, differences, and migration notes.

## Revision map

TODO

## Compatibility notes

TODO

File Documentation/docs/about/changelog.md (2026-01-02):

# **Changelog**

This changelog documents user-visible changes in Spikeling across hardware, firmware, and GUI releases.
It is organized to help educators and users keep experiments reproducible.

We follow a simple structure per release:

- **Added**: new features
- **Changed**: changes in behavior or defaults
- **Fixed**: bug fixes
- **Deprecated**: features planned for removal
- **Removed**: removed features
- **Security**: security-related changes

## **Unreleased**

### **Added**
- TODO

### **Changed**
- TODO

### **Fixed**
- TODO

## **v3.0.1**

### **Added**
- TODO: List major new features in the device, GUI, emulator, and imaging simulation.

### **Changed**
- TODO: Defaults or behavior changes (e.g., parameter ranges, data format changes, UI changes).

### **Fixed**
- TODO: High-impact bug fixes (e.g., plotting sync, recording issues, flashing reliability).

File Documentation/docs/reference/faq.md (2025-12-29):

# FAQ

Frequently asked questions (user-facing).

## Setup

TODO

## Experiments

TODO

## Troubleshooting

TODO

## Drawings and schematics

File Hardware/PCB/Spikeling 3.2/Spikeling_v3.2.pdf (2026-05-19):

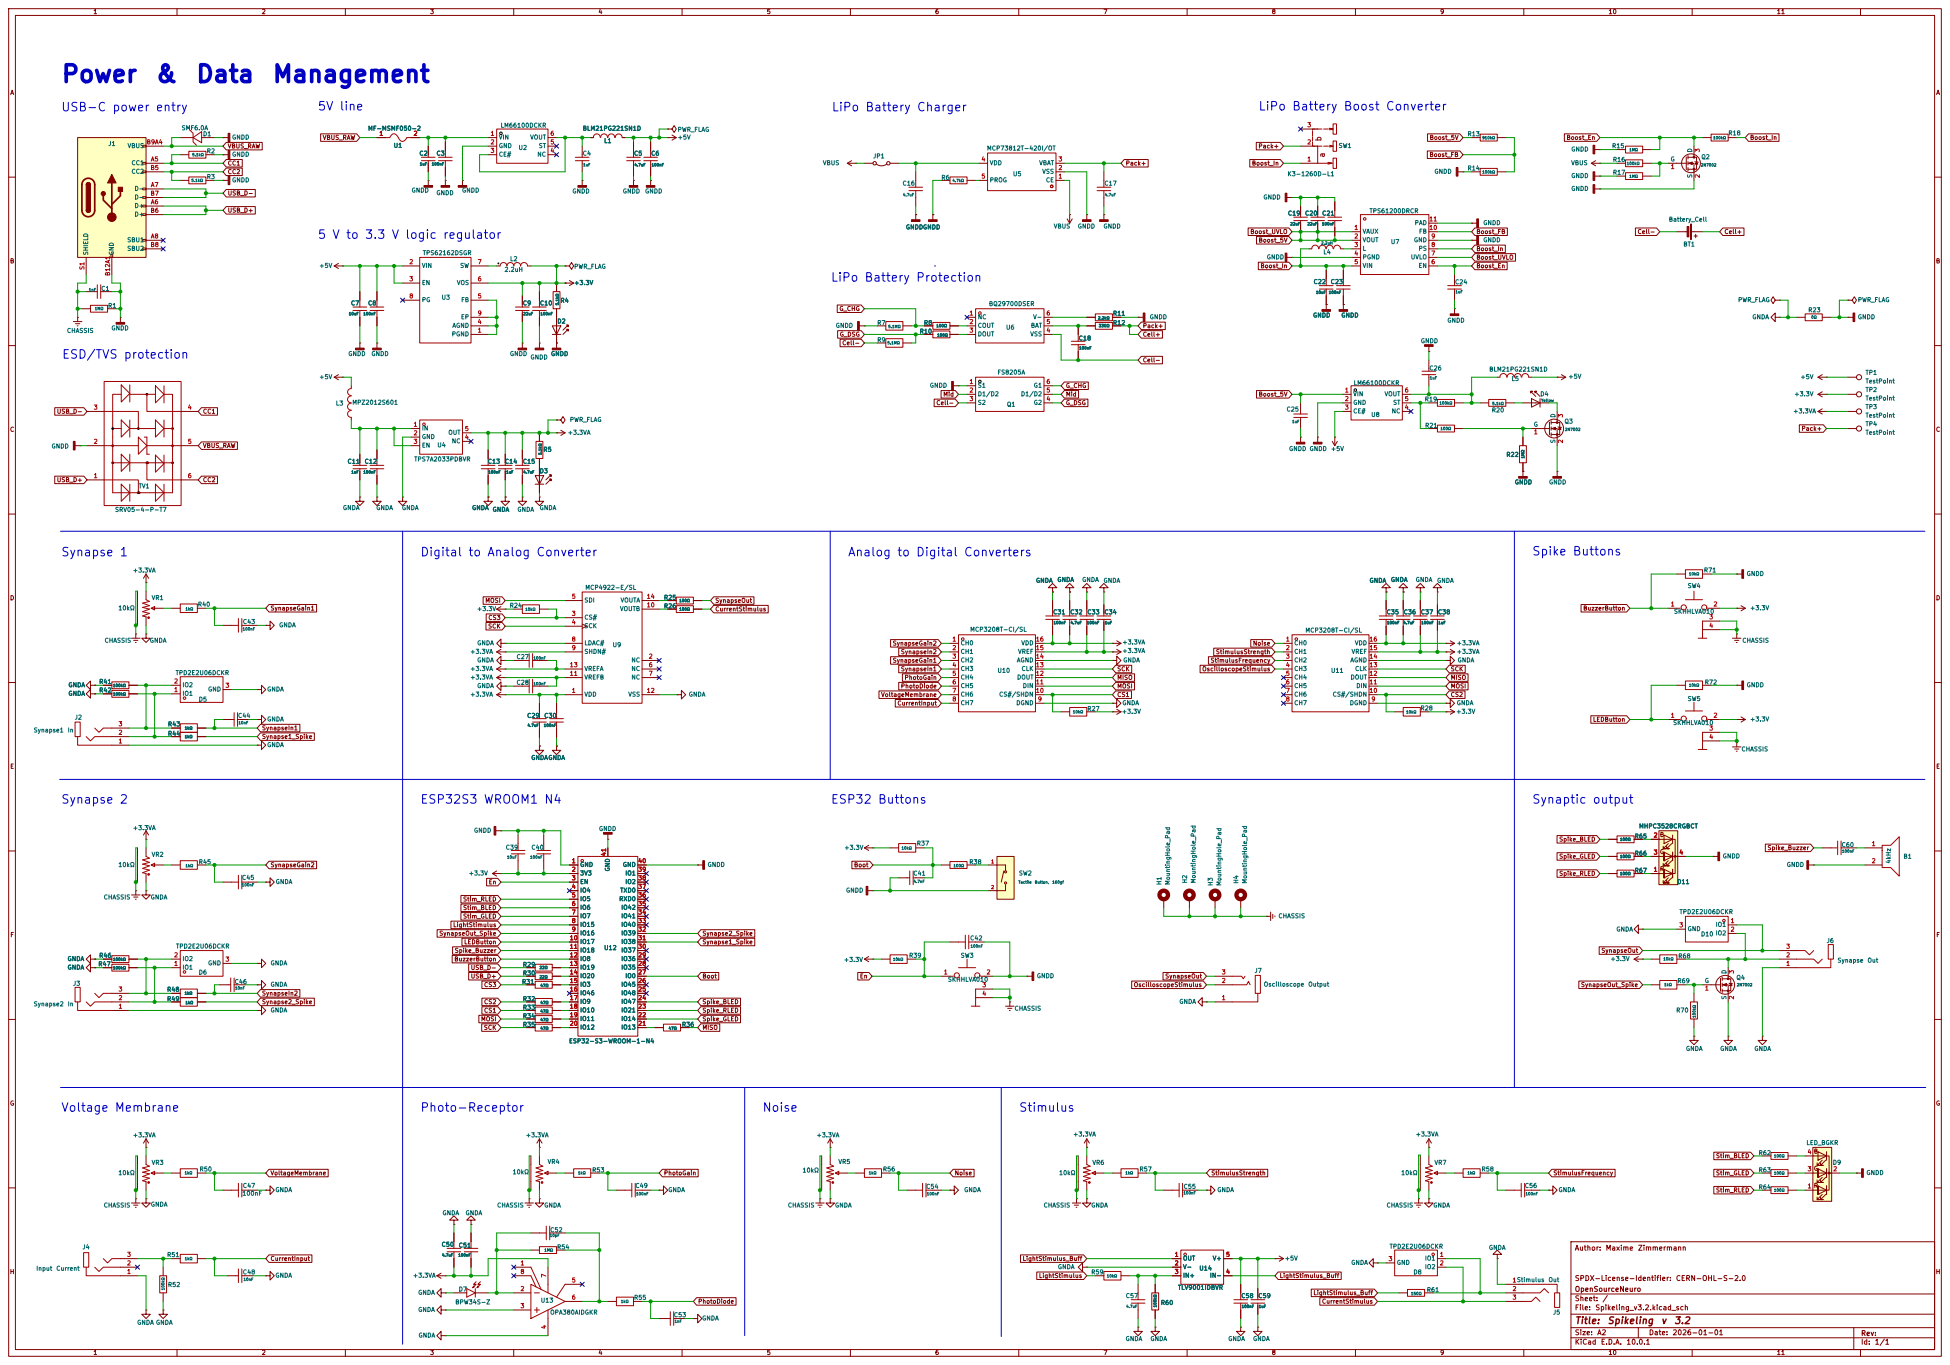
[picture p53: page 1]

Digital to Analog Converter

Analog to Digital Converters

SPDX-License-Identifier: CERN-OHL-S-2.0
OpenSourceNeuro
Sheet: /
File: Spikeling_v3.2.kicad_sch
Title: Spikeling v 3.2

Size: A2 | Rev:
KiCad E.D.A. 10.0.1 | Id: 1/1

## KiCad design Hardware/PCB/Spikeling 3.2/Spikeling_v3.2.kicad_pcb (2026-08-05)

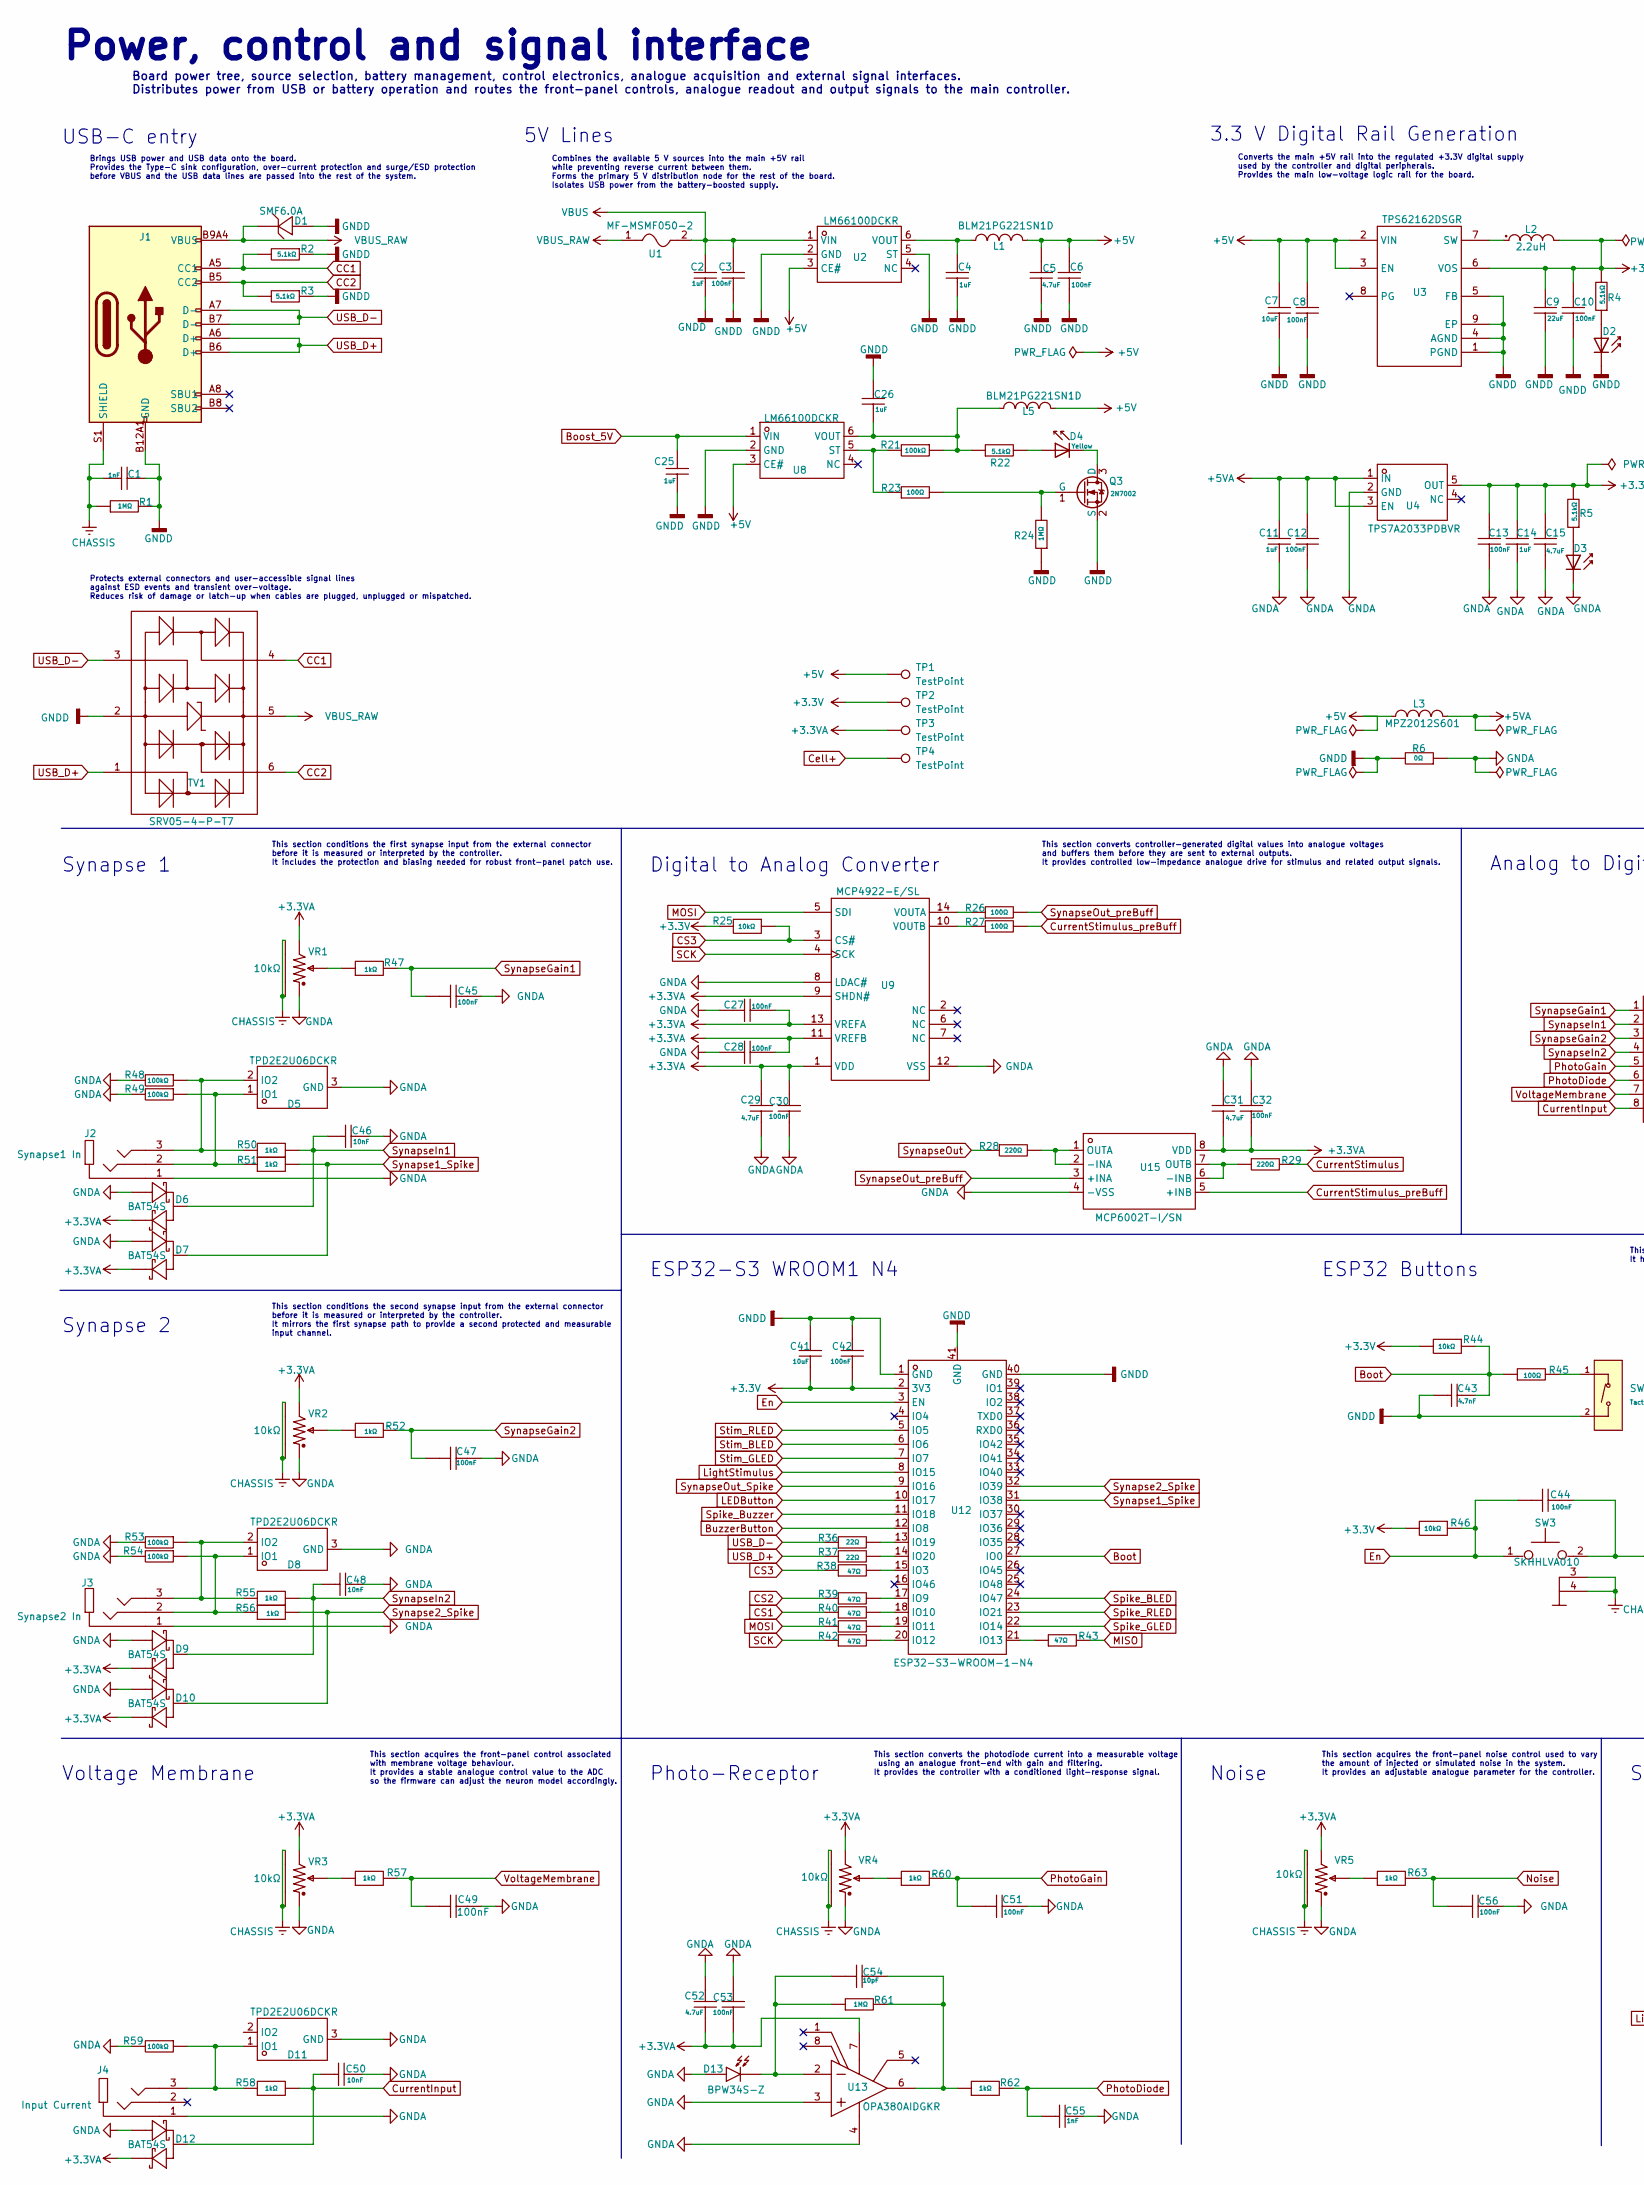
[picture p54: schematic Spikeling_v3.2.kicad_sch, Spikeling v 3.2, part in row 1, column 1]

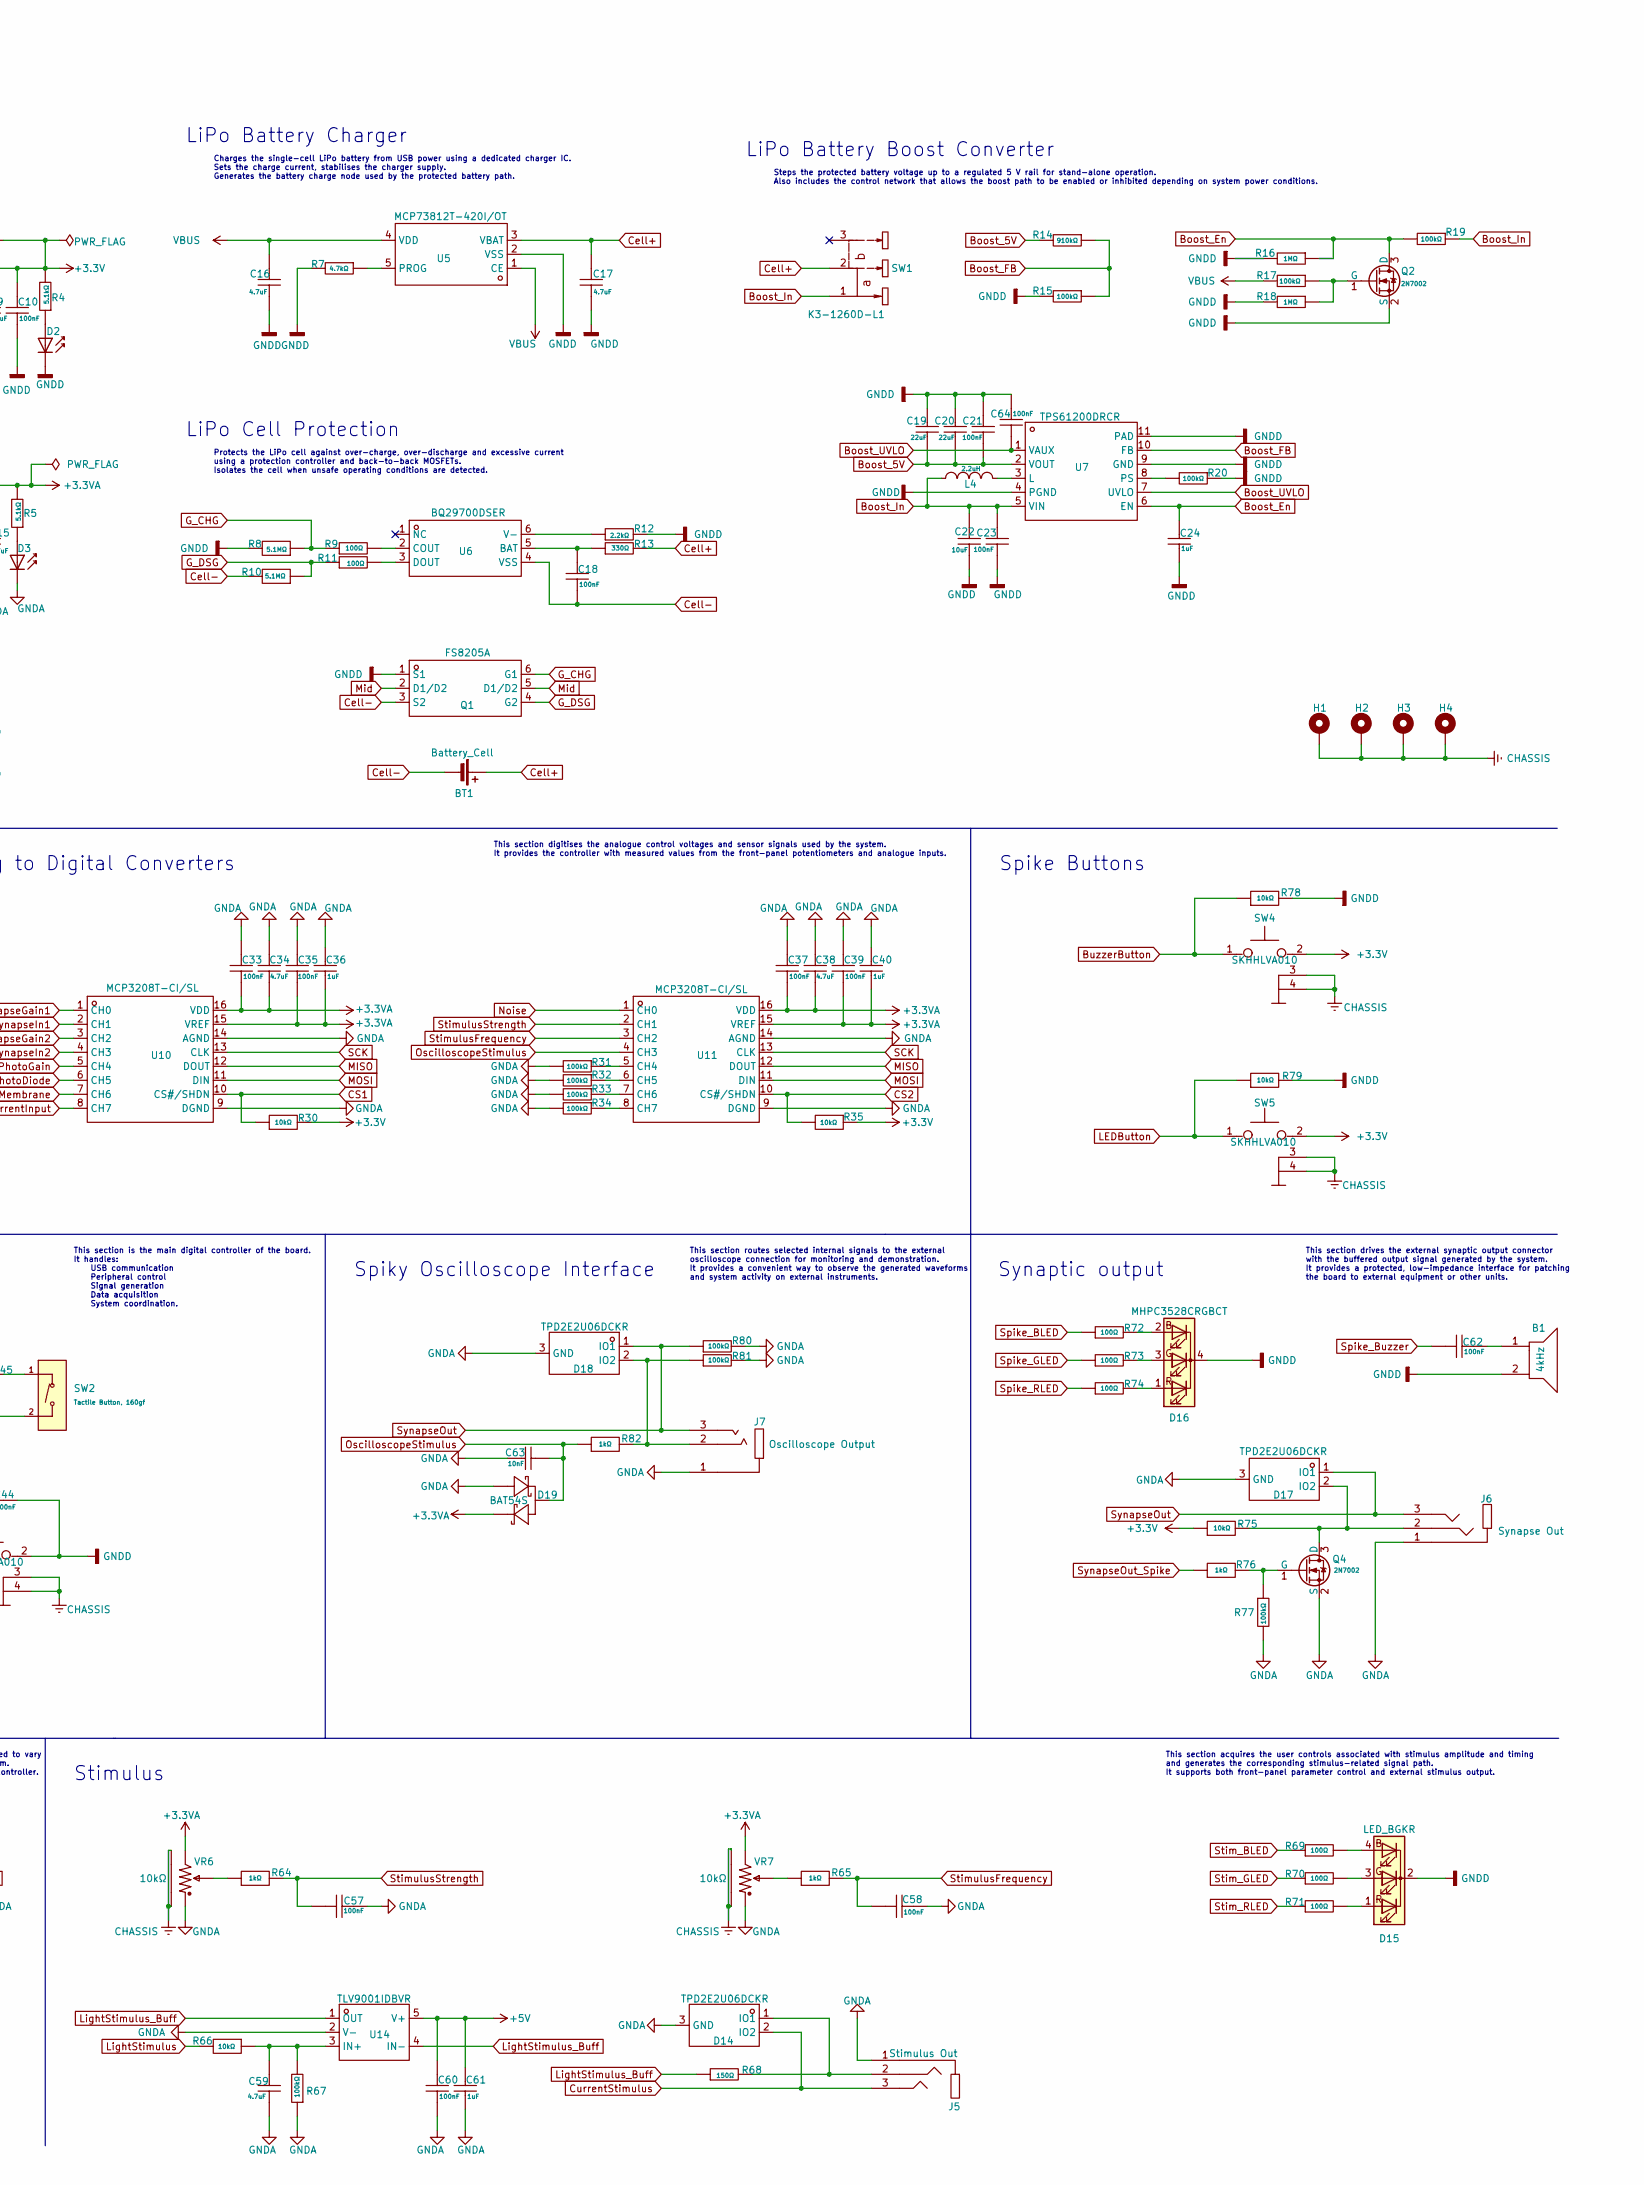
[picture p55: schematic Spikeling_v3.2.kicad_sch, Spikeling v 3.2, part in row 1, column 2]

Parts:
B1: 4kHz; BUZ-TH_L12.0-W12.0; LCSC Part # C7421651
BT1: Battery_Cell; JST_XH_B2B-XH-A_1x02_P2.50mm_Vertical; LCSC Part # C265283
C1, C55: 1nF; C_0603; TOLERANCE ±10%; MANUFACTURER PART CC0603KRX7R9BB102; LCSC PART NAME 1nF ±10% 50V
C2, C4, C11, C14, C24, C25, C26, C36, C40, C61: 1uF; C_0805; TOLERANCE ±10%; VOLTAGE RATING 50V; MANUFACTURER PART CL21B105KBFNNNE; LCSC PART NAME 1uF ±10% 50V
C3, C6, C8, C10, C12, C13, C18, C21, C23, C27, C28, C30, C32, C33, C35, C37, C39, C42, C44, C45, C47, C49, C51, C53, C56, C57, C58, C60, C62, C64: 100nF; C_0603; TOLERANCE ±10%; VOLTAGE RATING 50V; MANUFACTURER PART CL10B104KB8NNNC; LCSC PART NAME 100nF ±10% 50V
C5, C15, C16, C17, C29, C31, C34, C38, C52, C59: 4.7uF; C_0805; TOLERANCE ±10%; VOLTAGE RATING 35V; MANUFACTURER PART CS2012X7R475K350NRE; LCSC PART NAME 4.7uF ±10% 35V
C7, C22: 10uF; C_1206; TOLERANCE ±10%; VOLTAGE RATING 25V; MANUFACTURER PART TCC1206X7R106K250HT; LCSC PART NAME 10uF ±10% 25V
C9, C19, C20: 22uF; C_1206; TOLERANCE ±10%; VOLTAGE RATING 25V; MANUFACTURER PART CL31A226KAHNNNE; LCSC PART NAME 22uF ±10% 25V
C41: 10uF; C_0805; TOLERANCE ±10%; VOLTAGE RATING 50V; MANUFACTURER PART CL21A106KBYQNNE; LCSC PART NAME 10uF ±10% 50V
C43: 4.7nF; C_0603; TOLERANCE ±10%; VOLTAGE RATING 50V; MANUFACTURER PART 0603B472K500NT; LCSC PART NAME 4.7nF ±10% 50V
C46, C48, C50, C63: 10nF; C_0603; TOLERANCE ±10%; VOLTAGE RATING 50V; MANUFACTURER PART CC0603KRX7R9BB103; LCSC PART NAME 10nF ±10% 50V
C54: 10pF; C_0603; TOLERANCE ±5%; VOLTAGE RATING 50V; MANUFACTURER PART 0603CG100J500NT; LCSC PART NAME 10pF ±5% 50V
D1: SMF6.0A; D_SOD-123FL; CLAMPING VOLTAGE 10.3V; VOLTAGE - BREAKDOWN 7.37V; MANUFACTURER PART SMF6.0A; LCSC PART NAME 单向TVS 6V截止 峰值浪涌电流：19.4A@10/1000us
D2, D3: Red; D_0603; Part KT-0603R; LCSC Part # C2286
D4: Yellow; D_0603; Forward Voltage (VF) 1.6V~2.6V; Part NCD0603Y2; LCSC Part # C89811
D5, D8, D11, D14, D17, D18: TPD2E2U06DCKR; SC-70-3_L2.0-W1.3-P0.65-LS2.1-BL; BREAKDOWN VOLTAGE 6.5V; MANUFACTURER PART TPD2E2U06DCKR; LCSC PART NAME TPD2E2U06DCKR
D6, D7, D9, D10, D12, D19: BAT54S; SOT-23-3_L2.9-W1.3-P1.90-LS2.4-BR; VOLTAGE - FORWARD(VF@IF) 800mV@100mA; VOLTAGE - DC REVERSE(VR) 30V; MANUFACTURER PART BAT54S; LCSC PART NAME 电压:30V 电流:200mA
D13: BPW34S-Z; SENSOR-TH_BPW34S-Z; MANUFACTURER PART BPW34S-Z; LCSC PART NAME 920nm 频谱范围420nm~1120nm 反向电压32V
D15: LED_BGKR; LED_Kingbright_APFA3010_3x1.5mm_Horizontal
D16: MHPC3528CRGBCT; LED-SMD_4P-L3.2-W2.8-BL; LCSC PART NAME RGB三色 正贴
H1, H2, H3, H4: MountingHole_Pad; MountingHole_3.2mm_M3_DIN965_Pad
J1: Connector, USB-TYPE-C-16P; TYPE-C-SMD_HX-TYPE-C-16PIN; LCSC Part # C2927039
J2: Synapse1 In; AUDIO-SMD_HX-PJ-320A-3P-DIP; CURRENT RATING 500mA; VOLTAGE RATING (MAX) 30V; MANUFACTURER PART HX PJ-320A-3P DIP; LCSC PART NAME 3.5mm耳机座
J3: Synapse2 In; AUDIO-SMD_HX-PJ-320A-3P-DIP; CURRENT RATING 500mA; VOLTAGE RATING (MAX) 30V; MANUFACTURER PART HX PJ-320A-3P DIP; LCSC PART NAME 3.5mm耳机座
J4: Input Current; AUDIO-SMD_HX-PJ-320A-3P-DIP; CURRENT RATING 500mA; VOLTAGE RATING (MAX) 30V; MANUFACTURER PART HX PJ-320A-3P DIP; LCSC PART NAME 3.5mm耳机座
J5: Stimulus Out; AUDIO-SMD_HX-PJ-320A-3P-DIP; CURRENT RATING 500mA; VOLTAGE RATING (MAX) 30V; MANUFACTURER PART HX PJ-320A-3P DIP; LCSC PART NAME 3.5mm耳机座
J6: Synapse Out; AUDIO-SMD_HX-PJ-320A-3P-DIP; CURRENT RATING 500mA; VOLTAGE RATING (MAX) 30V; MANUFACTURER PART HX PJ-320A-3P DIP; LCSC PART NAME 3.5mm耳机座
J7: Oscilloscope Output; AUDIO-SMD_PJ-320B; CURRENT RATING (MAX) 200mA; VOLTAGE RATING (MAX) 30V; MANUFACTURER PART PJ-320B贴片; LCSC PART NAME 3.5mm耳机座
L1, L5: BLM21PG221SN1D; L0805; TOLERANCE ±25%; CURRENT RATING 2A; MANUFACTURER PART BLM21PG221SN1D; LCSC PART NAME 单路 0805磁珠 阻抗220Ω@100MHz
L2: 2.2uH; IND-SMD_L3.0-W3.0_XFL3012; TOLERANCE ±20%; CURRENT RATING 1.9A; MANUFACTURER PART XFL3012-222MEC; LCSC PART NAME 2.2uH ±20% 1.6A
L3: MPZ2012S601; L_0805; TOLERANCE ±25%; CURRENT RATING 2A; MANUFACTURER PART MPZ2012S601AT000; LCSC PART NAME 单路 0805磁珠 阻抗600Ω@100MHz
L4: 2.2uH; IND-SMD_L4.4-W4.0_PHC0420; TOLERANCE ±20%; CURRENT RATING 4.5A; MANUFACTURER PART APH0420T2R2M; LCSC PART NAME 2.2uH ±20% 5A
Q1: FS8205A; SOT-23-6_L2.9-W1.6-P0.95-LS2.8-BR; MANUFACTURER PART FS8205A; LCSC PART NAME 2个N沟道 耐压:20V 电流:6A
Q2, Q3, Q4: 2N7002; Q_SOT-23; Part 2N7002; LCSC Part # C8545
R1, R16, R18, R24, R61: 1MΩ; R_0603; TOLERANCE ±1%; MANUFACTURER PART RC0603FR-071ML; LCSC PART NAME 厚膜电阻 1MΩ ±1% 100mW
R2, R3, R4, R5, R22: 5.1kΩ; R_0603; TOLERANCE ±1%; VOLTAGE-SUPPLY(MAX) 75V; MANUFACTURER PART 0603WAF5101T5E; LCSC PART NAME 5.1kΩ ±1% 100mW 厚膜电阻
R6: 0Ω; R_0603; TOLERANCE ±1%; VOLTAGE-SUPPLY(MAX) 75V; MANUFACTURER PART 0603WAF0000T5E; LCSC PART NAME 0Ω ±1% 100mW 厚膜电阻
R7: 4.7kΩ; R_0603; TOLERANCE ±1%; VOLTAGE-SUPPLY(MAX) 75V; MANUFACTURER PART 0603WAF4701T5E; LCSC PART NAME 4.7kΩ ±1% 100mW 厚膜电阻
R8, R10: 5.1MΩ; R_0603; TOLERANCE ±1%; VOLTAGE-SUPPLY(MAX) 75V; MANUFACTURER PART AC0603FR-075M1L; LCSC PART NAME 厚膜电阻 5.1MΩ ±1% 100mW
R9, R11, R23, R26, R27, R45, R69, R70, R71, R72, R73, R74: 100Ω; R_0603; TOLERANCE ±1%; MANUFACTURER PART RC0603FR-07100RL; LCSC PART NAME 厚膜电阻 100Ω ±1% 100mW
R12: 2.2kΩ; R_0603; TOLERANCE ±1%; MANUFACTURER PART 0603WAF2201T5E; LCSC PART NAME 2.2kΩ ±1% 100mW 厚膜电阻
R13: 330Ω; R_0603; TOLERANCE ±1%; MANUFACTURER PART 0603WAF3300T5E; LCSC PART NAME 330Ω ±1% 100mW 厚膜电阻
R14: 910kΩ; R_0603; TOLERANCE ±1%; MANUFACTURER PART 0603WAF9103T5E; LCSC PART NAME 910kΩ ±1% 100mW 厚膜电阻
R15, R17, R19, R20, R21, R31, R32, R33, R34, R48, R49, R53, R54, R59, R67, R77, R80, R81: 100kΩ; R_0603; TOLERANCE ±1%; MANUFACTURER PART RC0603FR-07100KL; LCSC PART NAME 厚膜电阻 100kΩ ±1% 100mW
R25, R30, R35, R44, R46, R66, R75, R78, R79: 10kΩ; R_0603; TOLERANCE ±1%; VOLTAGE-SUPPLY(MAX) 75V; MANUFACTURER PART FRC0603F1002TS; LCSC PART NAME 10kΩ ±1% 100mW 厚膜电阻
R28, R29: 220Ω; R_0603; TOLERANCE ±1%; VOLTAGE-SUPPLY(MAX) 75V; MANUFACTURER PART RC0603FR-07220RL; LCSC PART NAME 厚膜电阻 220Ω ±1% 100mW
R36, R37: 22Ω; R_0603; TOLERANCE ±1%; MANUFACTURER PART 0603WAF220JT5E; LCSC PART NAME 22Ω ±1% 100mW 厚膜电阻
R38, R39, R40, R41, R42, R43: 47Ω; R_0603; TOLERANCE ±1%; VOLTAGE-SUPPLY(MAX) 75V; MANUFACTURER PART 0603WAF470JT5E; LCSC PART NAME 47Ω ±1% 100mW 厚膜电阻
R47, R50, R51, R52, R55, R56, R57, R58, R60, R62, R63, R64, R65, R76, R82: 1kΩ; R_0603; TOLERANCE ±1%; VOLTAGE-SUPPLY(MAX) 75V; MANUFACTURER PART FRC0603F1001TS; LCSC PART NAME 1kΩ ±1% 100mW 厚膜电阻
R68: 150Ω; R_0603; TOLERANCE ±1%; MANUFACTURER PART 0603WAF1500T5E; LCSC PART NAME 150Ω ±1% 100mW 厚膜电阻
SW1: K3-1260D-L1; SW-TH_K3-1260D-L1; CURRENT RATING 300mA; VOLTAGE RATING 6V; MANUFACTURER PART K3-1260D-L1; LCSC PART NAME 卧插双档 滑动开关
SW2: Tactile Button, 160gf; SW_TS-1088-AR02016; Part TS-1088-AR02016; LCSC Part # C720477
SW3, SW4, SW5: SKHHLVA010; KEY-TH_4P-L7.5-W6.8-P4.50-LS7.2; VOLTAGE RATING (DC) 12V; MANUFACTURER PART SKHHLVA010; LCSC PART NAME 6*6*5.85mm 卧插 轻触开关
TP1, TP2, TP3, TP4: TestPoint; TestPoint_Pad_D2.0mm
TV1: SRV05-4-P-T7; SOT-23-6_L2.9-W1.6-P0.95-LS2.8-BR; CLAMPING VOLTAGE 12V; VOLTAGE - BREAKDOWN 6V; MANUFACTURER PART SRV05-4-P-T7; LCSC Part ESD 5V截止 峰值浪涌电流：1A@8/20us
U1: MF-MSMF050-2; F1812; VOLTAGE - MAX 15V; MANUFACTURER PART MF-MSMF050-2; LCSC PART NAME 15V 500mA 1812自恢复
U2, U8: LM66100DCKR; SC-70-6_L2.0-W1.3-P0.65-LS2.1-BL; MANUFACTURER PART LM66100DCKR; LCSC PART NAME 5.5V 1.5A 低静态电流理想二极管
U3: TPS62162DSGR; WSON-8_L2.0-W2.0-P0.50-TL-EP; VOLTAGE - SUPPLY 3V~17V; OUTPUT VOLTAGE 3.3V; MANUFACTURER PART TPS62162DSGR; LCSC PART NAME 降压型 1A 3V~17V
U4: TPS7A2033PDBVR; SOT-23-5_L2.9-W1.6-P0.95-LS2.8-BR; OUTPUT VOLTAGE 3.3V; DROPOUT VOLTAGE 140mV@(300mA); MANUFACTURER PART TPS7A2033PDBVR; LCSC PART NAME 具有高 PSRR 的 300mA、超低噪声、低 IQ、低压降 (LDO) 线性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
U5: MCP73812T-420I/OT; SOT-23-5_L3.0-W1.7-P0.95-LS2.8-BR; VOLTAGE - SUPPLY 3.75V~6V; MANUFACTURER PART MCP73812T-420I/OT; LCSC PART NAME 单节锂离子/聚合物电池充电管理控制器
U6: BQ29700DSER; WSON-6_L1.5-W1.5-P0.50-TL; VOLTAGE - SUPPLY -300mV~8V; MANUFACTURER PART BQ29700DSER; LCSC PART NAME BQ29700DSER
U7: TPS61200DRCR; VSON-10_L3.0-W3.0-P0.50-TL-EP_TPS62410DRCR; VOLTAGE - SUPPLY 300mV~5.5V; OUTPUT VOLTAGE 1.8V~5.5V; MANUFACTURER PART TPS61200DRCR; LCSC PART NAME 低输入电压同步升压转换器
U9: MCP4922-E/SL; SOIC-14_L8.7-W3.9-P1.27-LS6.0-BL; VOLTAGE - SUPPLY 2.7V~5.5V; VOLTAGE REFERENCE External; MANUFACTURER PART MCP4922-E/SL; LCSC PART NAME MCP4922-E/SL
U10, U11: MCP3208T-CI/SL; SOIC-16_L9.9-W3.9-P1.27-LS6.0-BL; VOLTAGE - SUPPLY 2.7V~5.5V; MANUFACTURER PART MCP3208T-CI/SL; LCSC PART NAME MCP3208T-CI/SL
U12: ESP32-S3-WROOM-1-N4; WIFIM-SMD_ESP32-S3-WROOM-1-N8; MANUFACTURER PART ESP32-S3-WROOM-1-N4; LCSC PART NAME 通用型Wi-Fi+低功耗蓝牙MCU模组
U13: OPA380AIDGKR; VSSOP-8_L3.0-W3.0-P0.65-LS4.9-BL; MANUFACTURER PART OPA380AIDGKR; LCSC PART NAME OPA380AIDGKR
U14: TLV9001IDBVR; SOT-23-5_L3.0-W1.7-P0.95-LS2.8-BR; MANUFACTURER PART TLV9001IDBVR; LCSC PART NAME TLV9001IDBVR
U15: MCP6002T-I/SN; SOIC-8_L4.9-W3.9-P1.27-LS6.0-BL; INPUT VOLTAGE NOISE DEN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 28nV/√Hz@1kHz; MANUFACTURER PART MCP6002T-I/SN; LCSC PART NAME 1 MHz 低功耗运算放大器
VR1, VR2, VR3, VR4, VR6, VR7: 10kΩ; RES-TH_RK09D1130C2P; TOLERANCE ±20%; VOLTAGE RATING 20V; MANUFACTURER PART RK09D1130C3C; LCSC PART NAME 10kΩ ±20%
VR5: 10kΩ; RES-TH_RK09D1130C2P; TOLERANCE ±20%; MANUFACTURER PART RK09D1130C2P; LCSC PART NAME 10kΩ ±20%

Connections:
+3.3V: C9.2, C10.2, C41.1, C42.1, L2.2, R4.2, R25.2, R30.2, R35.1, R44.2, R46.2, R75.1, SW4.2, SW5.2, TP2.1 (1_1), U3.6 (VOS), U12.2 (3V3)
+3.3VA: C13.2, C14.2, C15.2, C27.1, C28.1, C29.2, C30.2, C31.1, C32.2, C33.1, C34.1, C35.1, C36.1, C37.1, C38.1, C39.1, C40.1, C52.1, C53.1, D6.2 (K), D7.2 (K), D9.2 (K), D10.2 (K), D12.2 (K), D19.2 (K), R5.2, TP3.1 (1_1), U4.5 (OUT), U9.1 (VDD), U9.9 (SHDN#), U9.11 (VREFB), U9.13 (VREFA), U10.15 (VREF), U10.16 (VDD), U11.15 (VREF), U11.16 (VDD), U13.7 (V+), U15.8 (VDD), VR1.3, VR2.3, VR3.3, VR4.3, VR5.3, VR6.3, VR7.3
+5V: C5.2, C6.2, C7.2, C8.2, C60.2, C61.2, L1.2, L3.1, L5.2, TP1.1 (1_1), U2.3 (CE#), U3.2 (VIN), U3.3 (EN), U8.3 (CE#), U14.5 (V+)
+5VA: C11.2, C12.2, L3.2, U4.1 (IN), U4.3 (EN)
Boost_5V: C19.1, C20.1, C21.1, C25.2, R14.2, U7.2 (VOUT), U8.1 (VIN)
Boost_En: C24.1, Q2.3 (D), R16.1, R19.2, U7.6 (EN)
Boost_FB: R14.1, R15.1, U7.10 (FB)
Boost_In: C22.2, C23.2, L4.1, R19.1, SW1.1, U7.5 (VIN)
Boost_UVLO: C64.1, U7.1 (VAUX), U7.7 (UVLO)
Boot: C43.1, R44.1, R45.1, U12.27 (IO0)
BuzzerButton: R78.1, SW4.1, U12.12 (IO8)
CC1: J1.A5 (CC1), R2.2, TV1.4
CC2: J1.B5 (CC2), R3.2, TV1.6
CHASSIS: C1.1, H1.1 (1_1), H2.1 (1_1), H3.1 (1_1), H4.1 (1_1), J1.S1 (SHIELD), R1.1, SW3.3, SW3.4, SW4.3, SW4.4, SW5.3, SW5.4, VR1.4, VR1.5, VR2.4, VR2.5, VR3.4, VR3.5, VR4.4, VR4.5, VR5.4, VR5.5, VR6.4, VR6.5, VR7.4, VR7.5
CS1: R30.1, R40.1, U10.10 (CS#/SHDN)
CS2: R35.2, R39.1, U11.10 (CS#/SHDN)
CS3: R25.1, R38.1, U9.3 (CS#)
Cell+: BT1.1 (+), C17.2, R13.2, SW1.2, TP4.1 (1_1), U5.3 (VBAT)
Cell-: BT1.2 (-), C18.1, Q1.3 (S2), R10.2, U6.4 (VSS)
CurrentInput: C50.2, D12.3, R58.2, U10.8 (CH7)
CurrentStimulus: D14.2 (IO2), J5.3 (T), R29.2
CurrentStimulus_preBuff: R27.2, U15.5 (+INB)
En: C44.1, R46.1, SW3.1, U12.3 (EN)
GNDA: C11.1, C12.1, C13.1, C14.1, C15.1, C27.2, C28.2, C29.1, C30.1, C31.2, C32.1, C33.2, C34.2, C35.2, C36.2, C37.2, C38.2, C39.2, C40.2, C45.1, C46.2, C47.1, C48.2, C49.1, C50.1, C51.1, C52.2, C53.2, C55.1, C56.1, C57.1, C58.1, C59.1, C60.1, C61.1, C63.1, D3.1, D5.3 (GND), D6.1 (A), D7.1 (A), D8.3 (GND), D9.1 (A), D10.1 (A), D11.3 (GND), D12.1 (A), D13.1 (A), D14.3 (GND), D17.3 (GND), D18.3 (GND), D19.1 (A), J2.1 (S), J3.1 (S), J4.1 (S), J5.1 (S), J6.1 (S), J7.1, Q4.2 (S), R6.1, R31.2, R32.2, R33.2, R34.2, R48.2, R49.2, R53.2, R54.2, R59.2, R67.1, R77.2, R80.2, R81.2, U4.2 (GND), U9.8 (LDAC#), U9.12 (VSS), U10.9 (DGND), U10.14 (AGND), U11.9 (DGND), U11.14 (AGND), U13.3 (IN+), U13.4 (V-), U14.2 (V-), U15.4 (-VSS), VR1.1, VR2.1, VR3.1, VR4.1, VR5.1, VR6.1, VR7.1
GNDD: B1.2, C1.2, C2.1, C3.1, C4.1, C5.1, C6.1, C7.1, C8.1, C9.1, C10.1, C16.1, C17.1, C19.2, C20.2, C21.2, C22.1, C23.1, C24.2, C25.1, C26.2, C41.2, C42.2, C43.2, C44.2, C64.2, D1.2 (A), D2.1, D15.2 (K), D16.4 (K), J1.A12B1 (GND), J1.B12A1 (GND), Q1.1 (S1), Q2.2 (S), Q3.2 (S), R1.2, R2.1, R3.1, R6.2, R7.2, R8.2, R12.2, R15.2, R16.2, R18.2, R20.1, R24.1, R78.2, R79.2, SW2.2 (B), SW3.2, TV1.2, U2.2 (GND), U2.5 (ST), U3.1 (PGND), U3.4 (AGND), U3.5 (FB), U3.9 (EP), U5.2 (VSS), U7.4 (PGND), U7.9 (GND), U7.11 (PAD), U8.2 (GND), U12.1 (GND), U12.40 (GND), U12.41 (GND)
G_CHG: Q1.6 (G1), R8.1, R9.1
G_DSG: Q1.4 (G2), R10.1, R11.1
LEDButton: R79.1, SW5.1, U12.10 (IO17)
LightStimulus: R66.2, U12.8 (IO15)
LightStimulus_Buff: R68.1, U14.1 (OUT), U14.4 (IN-)
MISO: R43.2, U10.12 (DOUT), U11.12 (DOUT)
MOSI: R41.1, U9.5 (SDI), U10.11 (DIN), U11.11 (DIN)
Mid: Q1.2 (D1/D2), Q1.5 (D1/D2)
unnamed: B1.1, C62.2
unnamed: D2.2, R4.1
unnamed: D3.2, R5.1
unnamed: D4.2, R22.2
unnamed: D5.1 (IO1), J2.2 (R), R49.1, R51.1
unnamed: D5.2 (IO2), J2.3 (T), R48.1, R50.1
unnamed: D8.1 (IO1), J3.2 (R), R54.1, R56.1
unnamed: D8.2 (IO2), J3.3 (T), R53.1, R55.1
unnamed: D11.1 (IO1), J4.3 (T), R58.1, R59.1
unnamed: C54.1, D13.2 (C), R61.1, U13.2 (IN-)
unnamed: D14.1 (IO1), J5.2 (R), R68.2
unnamed: D15.4 (BA), R69.2
unnamed: D15.3 (GA), R70.2
unnamed: D15.1 (RA), R71.2
unnamed: D16.2 (BA), R72.2
unnamed: D16.3 (GA), R73.2
unnamed: D16.1 (RA), R74.2
unnamed: D17.2 (IO2), J6.2 (R), Q4.3 (D), R75.2
unnamed: D18.2 (IO2), J7.2, R81.1, R82.2
unnamed: Q2.1 (G), R17.1, R18.1
unnamed: D4.1, Q3.3 (D)
unnamed: Q3.1 (G), R23.2, R24.2
unnamed: Q4.1 (G), R76.2, R77.1
unnamed: R47.1, VR1.2
unnamed: R52.1, VR2.2
unnamed: R57.1, VR3.2
unnamed: R60.1, VR4.2
unnamed: R63.1, VR5.2
unnamed: R64.1, VR6.2
unnamed: R65.1, VR7.2
unnamed: R45.2, SW2.1 (A)
unnamed: C4.2, L1.1, U2.6 (VOUT)
unnamed: L2.1, U3.7 (SW)
unnamed: R7.1, U5.5 (PROG)
unnamed: C18.2, R13.1, U6.5 (BAT)
unnamed: R9.2, U6.2 (COUT)
unnamed: R11.2, U6.3 (DOUT)
unnamed: R12.1, U6.6 (V-)
unnamed: L4.2, U7.3 (L)
unnamed: R20.2, U7.8 (PS)
unnamed: R21.2, R23.1, U8.5 (ST)
unnamed: C26.1, L5.1, R21.1, R22.1, U8.6 (VOUT)
unnamed: R26.1, U9.14 (VOUTA)
unnamed: R27.1, U9.10 (VOUTB)
unnamed: R31.1, U11.5 (CH4)
unnamed: R32.1, U11.6 (CH5)
unnamed: R33.1, U11.7 (CH6)
unnamed: R34.1, U11.8 (CH7)
unnamed: R38.2, U12.15 (IO3)
unnamed: R39.2, U12.17 (IO9)
unnamed: R40.2, U12.18 (IO10)
unnamed: R41.2, U12.19 (IO11)
unnamed: R42.2, U12.20 (IO12)
unnamed: R43.1, U12.21 (IO13)
unnamed: R36.2, U12.13 (IO19)
unnamed: R37.2, U12.14 (IO20)
unnamed: C54.2, R61.2, R62.1, U13.6 (OUT)
unnamed: C59.2, R66.1, R67.2, U14.3 (IN+)
unnamed: R28.2, U15.1 (OUTA), U15.2 (-INA)
unnamed: R29.1, U15.6 (-INB), U15.7 (OUTB)
Noise: C56.2, R63.2, U11.1 (CH0)
OscilloscopeStimulus: C63.2, D19.3, R82.1, U11.4 (CH3)
PhotoDiode: C55.2, R62.2, U10.6 (CH5)
PhotoGain: C51.2, R60.2, U10.5 (CH4)
SCK: R42.1, U9.4 (SCK), U10.13 (CLK), U11.13 (CLK)
Spike_BLED: R72.1, U12.24 (IO47)
Spike_Buzzer: C62.1, U12.11 (IO18)
Spike_GLED: R73.1, U12.22 (IO14)
Spike_RLED: R74.1, U12.23 (IO21)
Stim_BLED: R69.1, U12.6 (IO6)
Stim_GLED: R70.1, U12.7 (IO7)
Stim_RLED: R71.1, U12.5 (IO5)
StimulusFrequency: C58.2, R65.2, U11.3 (CH2)
StimulusStrength: C57.2, R64.2, U11.2 (CH1)
Synapse1_Spike: D7.3, R51.2, U12.31 (IO38)
Synapse2_Spike: D10.3, R56.2, U12.32 (IO39)
SynapseGain1: C45.2, R47.2, U10.1 (CH0)
SynapseGain2: C47.2, R52.2, U10.3 (CH2)
SynapseIn1: C46.1, D6.3, R50.2, U10.2 (CH1)
SynapseIn2: C48.1, D9.3, R55.2, U10.4 (CH3)
SynapseOut: D17.1 (IO1), D18.1 (IO1), J6.3 (T), J7.3, R28.1, R80.1
SynapseOut_Spike: R76.1, U12.9 (IO16)
SynapseOut_preBuff: R26.2, U15.3 (+INA)
USB_D+: J1.A6 (D+), J1.B6 (D+), R37.1, TV1.1
USB_D-: J1.A7 (D-), J1.B7 (D-), R36.1, TV1.3
VBUS: C2.2, C3.2, C16.2, R17.2, U1.2, U2.1 (VIN), U5.1 (CE), U5.4 (VDD)
VBUS_RAW: D1.1 (C), J1.A9B4 (VBUS), J1.B9A4 (VBUS), TV1.5, U1.1
VoltageMembrane: C49.2, R57.2, U10.7 (CH6)

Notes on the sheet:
Spike Buttons
Board power tree, source selection, battery management, control electronics, analogue acquisition and external signal interfaces. Distributes power from USB or battery operation and routes the front-panel controls, analogue readout and output signals to the main controller.
LiPo Battery Charger
Synapse 1
This section converts the photodiode current into a measurable voltage using an analogue front-end with gain and filtering. It provides the controller with a conditioned light-response signal.
This section acquires the front-panel control associated with membrane voltage behaviour. It provides a stable analogue control value to the ADC so the firmware can adjust the neuron model accordingly.
Combines the available 5 V sources into the main +5V rail while preventing reverse current between them. Forms the primary 5 V distribution node for the rest of the board. Isolates USB power from the battery-boosted supply.
This section drives the external synaptic output connector with the buffered output signal generated by the system. It provides a protected, low-impedance interface for patching the board to external equipment or other units.
ESP32 Buttons
This section converts controller-generated digital values into analogue voltages and buffers them before they are sent to external outputs. It provides controlled low-impedance analogue drive for stimulus and related output signals.
Converts the main +5V rail into the regulated +3.3V digital supply used by the controller and digital peripherals. Provides the main low-voltage logic rail for the board.
Charges the single-cell LiPo battery from USB power using a dedicated charger IC. Sets the charge current, stabilises the charger supply. Generates the battery charge node used by the protected battery path.
This section is the main digital controller of the board. It handles: USB communication Peripheral control Signal generation Data acquisition System coordination.
This section conditions the first synapse input from the external connector before it is measured or interpreted by the controller. It includes the protection and biasing needed for robust front-panel patch use.
This section digitises the analogue control voltages and sensor signals used by the system. It provides the controller with measured values from the front-panel potentiometers and analogue inputs.
Synapse 2
LiPo Battery Boost Converter
Analog to Digital Converters
Voltage Membrane
LiPo Cell Protection
This section routes selected internal signals to the external oscilloscope connection for monitoring and demonstration. It provides a convenient way to observe the generated waveforms and system activity on external instruments.
3.3 V Digital Rail Generation
Noise
Protects external connectors and user-accessible signal lines against ESD events and transient over-voltage. Reduces risk of damage or latch-up when cables are plugged, unplugged or mispatched.
Steps the protected battery voltage up to a regulated 5 V rail for stand-alone operation. Also includes the control network that allows the boost path to be enabled or inhibited depending on system power conditions.
Stimulus
This section acquires the front-panel noise control used to vary the amount of injected or simulated noise in the system. It provides an adjustable analogue parameter for the controller.
Digital to Analog Converter
This section acquires the user controls associated with stimulus amplitude and timing and generates the corresponding stimulus-related signal path. It supports both front-panel parameter control and external stimulus output.
Brings USB power and USB data onto the board. Provides the Type-C sink configuration, over-current protection and surge/ESD protection before VBUS and the USB data lines are passed into the rest of the system.
5V Lines
Photo-Receptor
ESP32-S3 WROOM1 N4
Synaptic output
Spiky Oscilloscope Interface
Protects the LiPo cell against over-charge, over-discharge and excessive current using a protection controller and back-to-back MOSFETs. Isolates the cell when unsafe operating conditions are detected.
Power, control and signal interface
USB-C entry
This section conditions the second synapse input from the external connector before it is measured or interpreted by the controller. It mirrors the first synapse path to provide a second protected and measurable input channel.

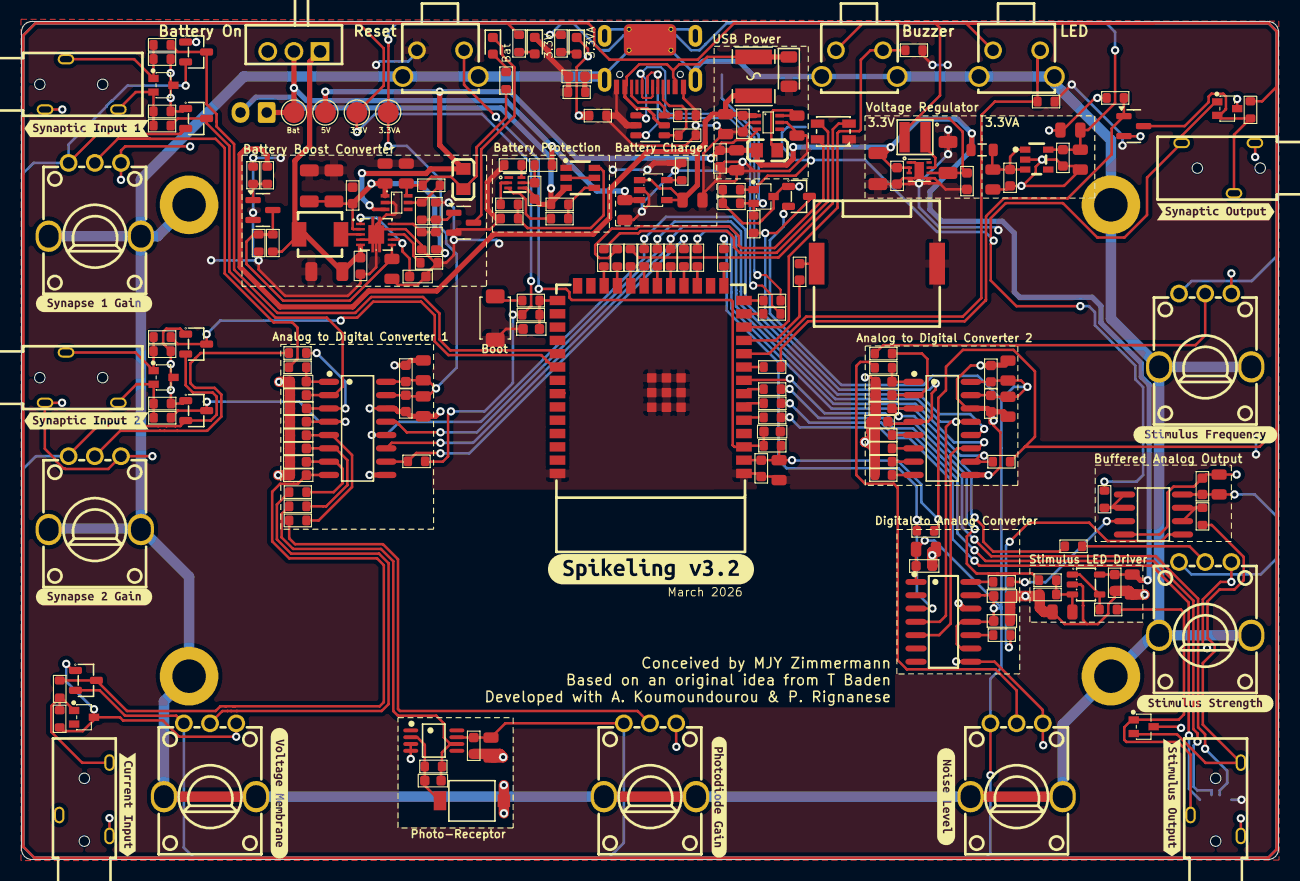
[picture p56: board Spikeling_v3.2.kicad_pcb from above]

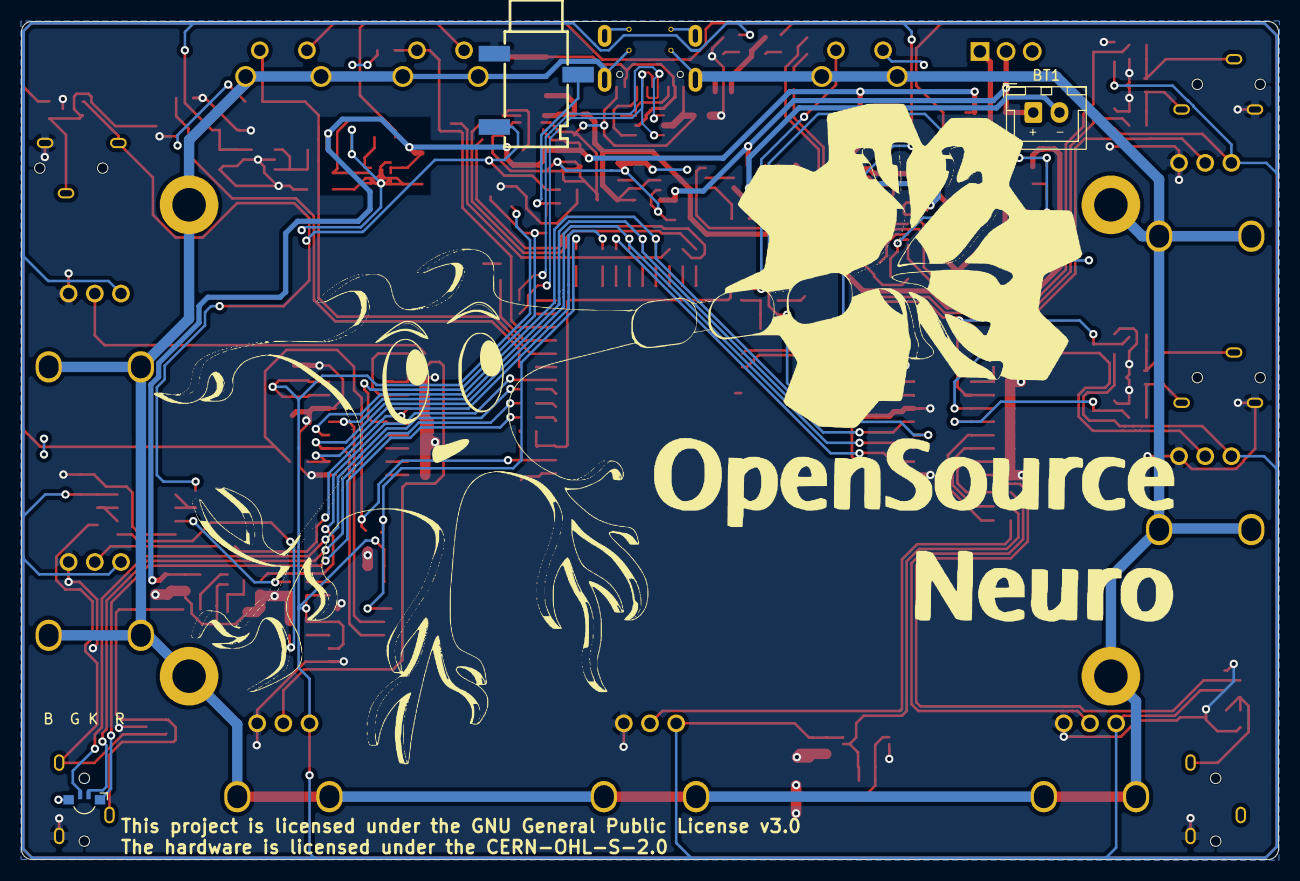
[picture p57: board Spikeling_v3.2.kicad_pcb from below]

Board: 2 copper layers, 120.0 x 80.0 mm, 232 parts (3 on the bottom side), 121 nets.

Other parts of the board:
kibuzzard-699ADA5F: G***; kibuzzard-699ADA5F
kibuzzard-699ADA80: G***; kibuzzard-699ADA80
kibuzzard-699ADAA1: G***; kibuzzard-699ADAA1
kibuzzard-699ADACE: G***; kibuzzard-699ADACE
kibuzzard-699ADAEF: G***; kibuzzard-699ADAEF
kibuzzard-699ADB2E: G***; kibuzzard-699ADB2E
kibuzzard-699ADB4A: G***; kibuzzard-699ADB4A
kibuzzard-699ADBA0: G***; kibuzzard-699ADBA0
kibuzzard-699ADBCD: G***; kibuzzard-699ADBCD
kibuzzard-699ADBE4: G***; kibuzzard-699ADBE4
kibuzzard-699ADC07: G***; kibuzzard-699ADC07
kibuzzard-699ADC8D: G***; kibuzzard-699ADC8D
kibuzzard-699AE09E: G***; kibuzzard-699AE09E

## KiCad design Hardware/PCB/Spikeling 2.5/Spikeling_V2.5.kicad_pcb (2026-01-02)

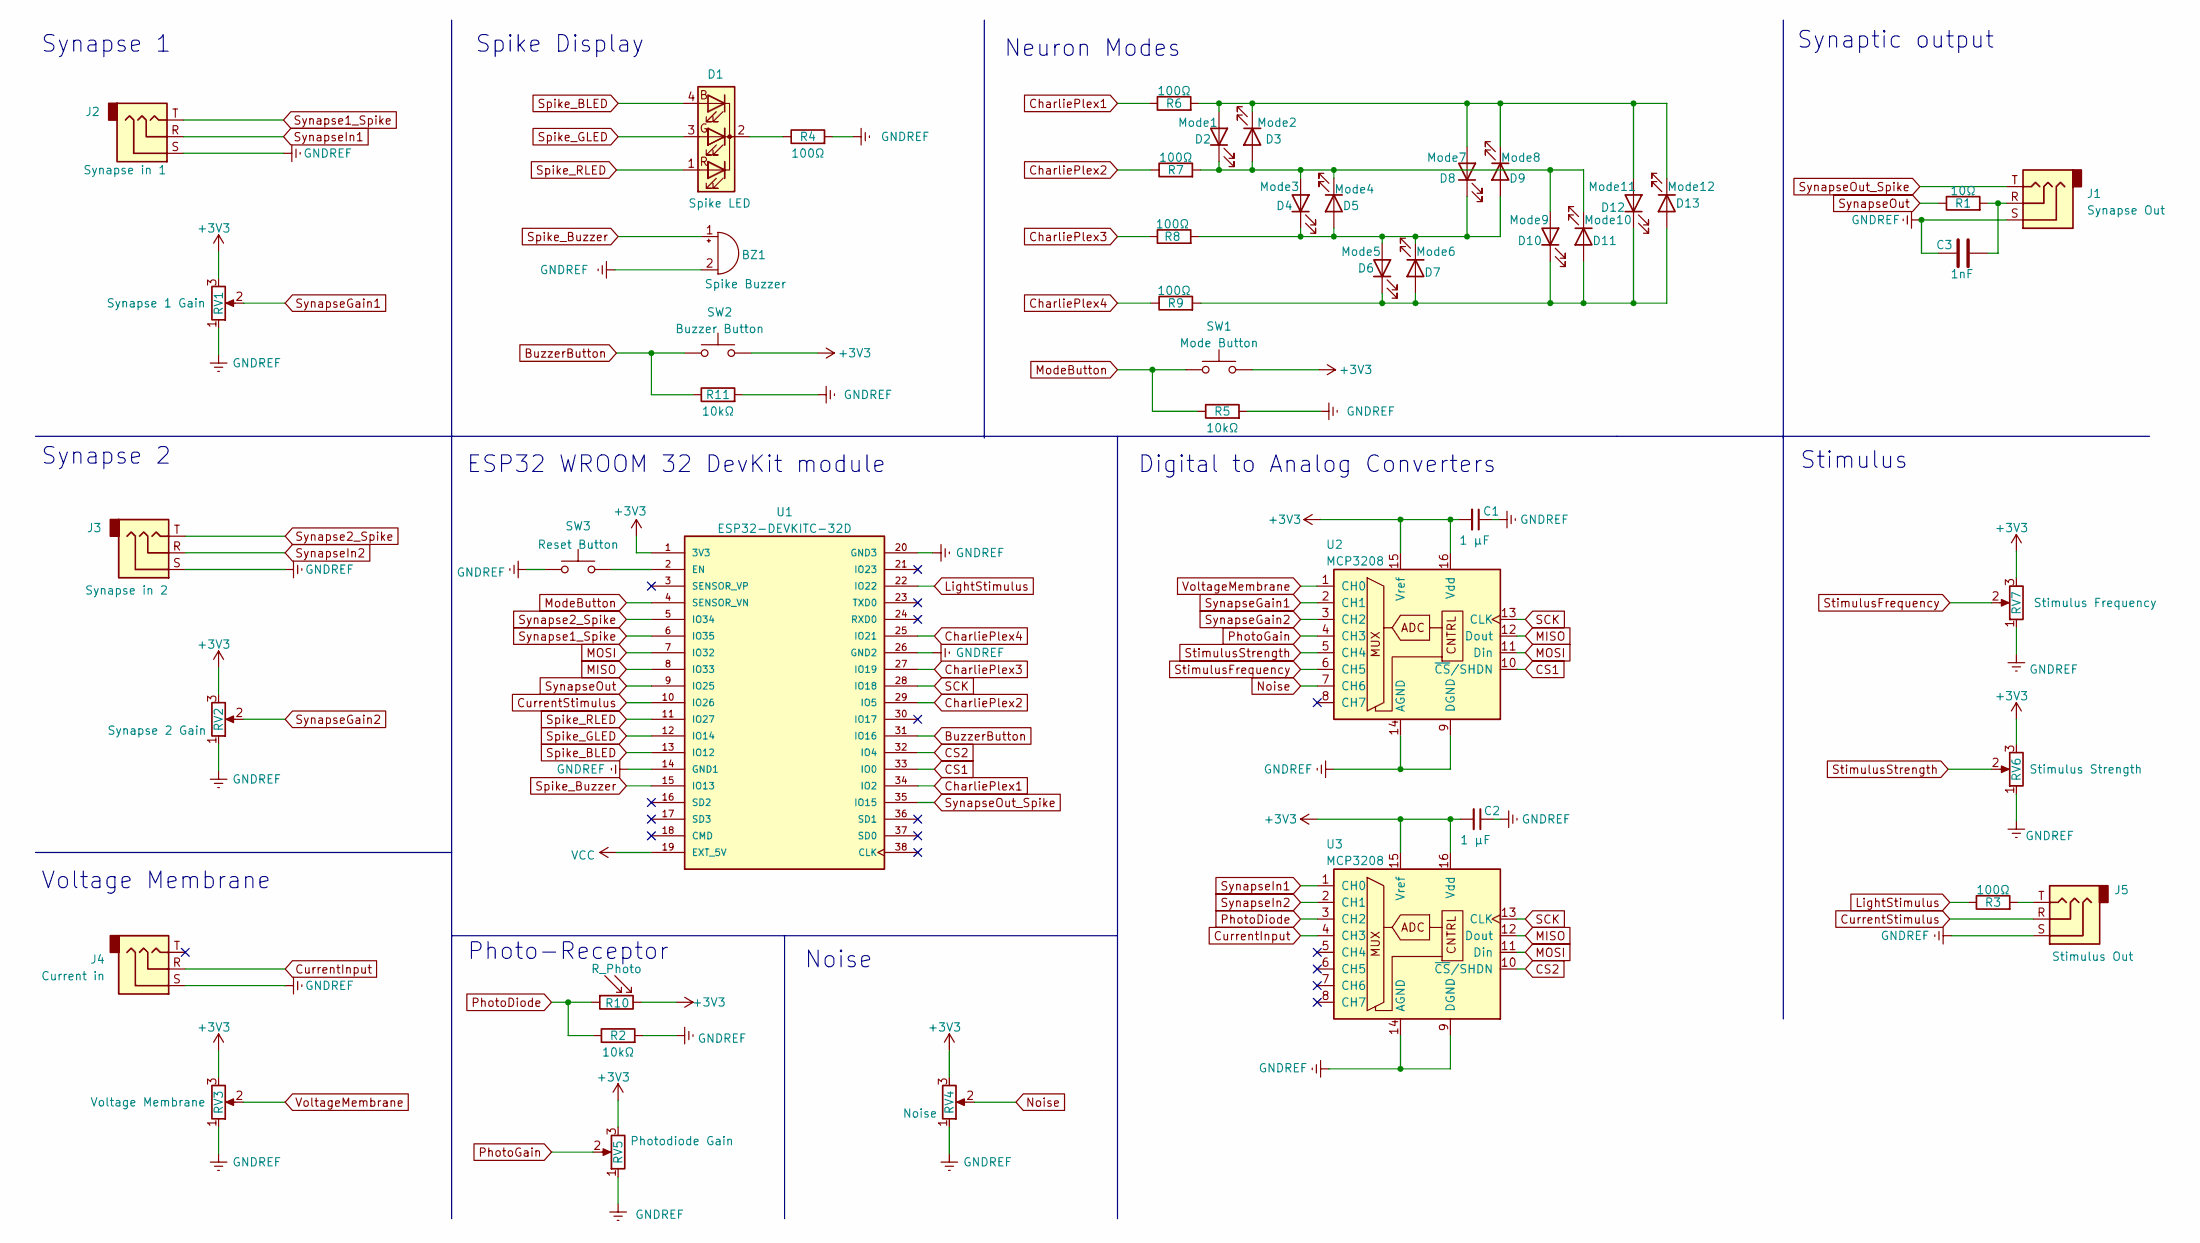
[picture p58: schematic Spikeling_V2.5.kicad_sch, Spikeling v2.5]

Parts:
BZ1: Spike Buzzer; Buzzer_11.5x9.5RM5
C1, C2: 1 μF; CP_Radial_D4.0mm_P2.00mm
C3: 1nF; CP_Radial_D4.0mm_P2.00mm
D1: Spike LED; LED_D5.0mm-4_RGB_Wide_Pins
D2: Mode1; LED_D3.0mm
D3: Mode2; LED_D3.0mm
D4: Mode3; LED_D3.0mm
D5: Mode4; LED_D3.0mm
D6: Mode5; LED_D3.0mm
D7: Mode6; LED_D3.0mm
D8: Mode7; LED_D3.0mm
D9: Mode8; LED_D3.0mm
D10: Mode9; LED_D3.0mm
D11: Mode10; LED_D3.0mm
D12: Mode11; LED_D3.0mm
D13: Mode12; LED_D3.0mm
J1: Synapse Out; Spikeling Audio Jack 3.5mm
J2: Synapse in 1; Spikeling Audio Jack 3.5mm
J3: Synapse in 2; Spikeling Audio Jack 3.5mm
J4: Current in; Spikeling Audio Jack 3.5mm
J5: Stimulus Out; Spikeling Audio Jack 3.5mm
R1: 10Ω; R_Axial_DIN0207_L6.3mm_D2.5mm_P10.16mm_Horizontal
R2, R5, R11: 10kΩ; R_Axial_DIN0207_L6.3mm_D2.5mm_P10.16mm_Horizontal
R3, R4, R6, R7, R8, R9: 100Ω; R_Axial_DIN0207_L6.3mm_D2.5mm_P10.16mm_Horizontal
R10: R_Photo; Photoresistor_3.4
RV1: Synapse 1 Gain; Spikeling Potentiometer
RV2: Synapse 2 Gain; Spikeling Potentiometer
RV3: Voltage Membrane; Spikeling Potentiometer
RV4: Noise; Spikeling Potentiometer
RV5: Photodiode Gain; Spikeling Potentiometer
RV6: Stimulus Strength; Spikeling Potentiometer
RV7: Stimulus Frequency; Spikeling Potentiometer
SW1: Mode Button; SW_PUSH_6mm_H13mm
SW2: Buzzer Button; Spikeling reset button
SW3: Reset Button; Spikeling reset button
U1: ESP32-DEVKITC-32D; MODULE_ESP32-DEVKITC-32D; PARTREV 4
U2, U3: MCP3208; DIP-16_W7.62mm

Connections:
+3V3: C1.2, C2.2, R10.2, RV1.3, RV2.3, RV3.3, RV4.3, RV5.3, RV6.3, RV7.3, SW1.2, SW2.2, U1.1 (3V3), U2.15 (Vref), U2.16 (Vdd), U3.15 (Vref), U3.16 (Vdd)
BuzzerButton: R11.1, SW2.1, U1.31 (IO16)
CS1: U1.33 (IO0), U2.10 (~CS/SHDN)
CS2: U1.32 (IO4), U3.10 (~CS/SHDN)
CharliePlex1: R6.1, U1.34 (IO2)
CharliePlex2: R7.1, U1.29 (IO5)
CharliePlex3: R8.1, U1.27 (IO19)
CharliePlex4: R9.1, U1.25 (IO21)
CurrentInput: J4.R, U3.4 (CH3)
CurrentStimulus: J5.R, U1.10 (IO26)
GNDREF: BZ1.2 (+), C1.1, C2.1, C3.1, J1.S, J2.S, J3.S, J4.S, J5.S, R2.2, R4.2, R5.2, R11.2, RV1.1, RV2.1, RV3.1, RV4.1, RV5.1, RV6.1, RV7.1, SW3.1, U1.14 (GND1), U1.20 (GND3), U1.26 (GND2), U2.9 (DGND), U2.14 (AGND), U3.9 (DGND), U3.14 (AGND)
LightStimulus: R3.1, U1.22 (IO22)
MISO: U1.8 (IO33), U2.12 (Dout), U3.12 (Dout)
MOSI: U1.7 (IO32), U2.11 (Din), U3.11 (Din)
ModeButton: R5.1, SW1.1, U1.4 (SENSOR_VN)
unnamed: C3.2, J1.R, R1.2
unnamed: D1.2 (K), R4.1
unnamed: D4.1 (K), D5.2 (A), D6.2 (A), D7.1 (K), D8.1 (K), D9.2 (A), R8.2
unnamed: D2.1 (K), D3.2 (A), D4.2 (A), D5.1 (K), D10.2 (A), D11.1 (K), R7.2
unnamed: D6.1 (K), D7.2 (A), D10.1 (K), D11.2 (A), D12.1 (K), D13.2 (A), R9.2
unnamed: D2.2 (A), D3.1 (K), D8.2 (A), D9.1 (K), D12.2 (A), D13.1 (K), R6.2
unnamed: J5.T, R3.2
unnamed: SW3.2, U1.2 (EN)
Noise: RV4.2, U2.7 (CH6)
PhotoDiode: R2.1, R10.1, U3.3 (CH2)
PhotoGain: RV5.2, U2.4 (CH3)
SCK: U1.28 (IO18), U2.13 (CLK), U3.13 (CLK)
Spike_BLED: D1.4 (BA), U1.13 (IO12)
Spike_Buzzer: BZ1.1 (-), U1.15 (IO13)
Spike_GLED: D1.3 (GA), U1.12 (IO14)
Spike_RLED: D1.1 (RA), U1.11 (IO27)
StimulusFrequency: RV7.2, U2.6 (CH5)
StimulusStrength: RV6.2, U2.5 (CH4)
Synapse1_Spike: J2.T, U1.6 (IO35)
Synapse2_Spike: J3.T, U1.5 (IO34)
SynapseGain1: RV1.2, U2.2 (CH1)
SynapseGain2: RV2.2, U2.3 (CH2)
SynapseIn1: J2.R, U3.1 (CH0)
SynapseIn2: J3.R, U3.2 (CH1)
SynapseOut: R1.1, U1.9 (IO25)
SynapseOut_Spike: J1.T, U1.35 (IO15)
VCC: U1.19 (EXT_5V)
VoltageMembrane: RV3.2, U2.1 (CH0)

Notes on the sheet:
Digital to Analog Converters
Noise
ESP32 WROOM 32 DevKit module
Photo-Receptor
Neuron Modes
Stimulus
Synapse 2
Synaptic output
Spike Display
Synapse 1
Voltage Membrane

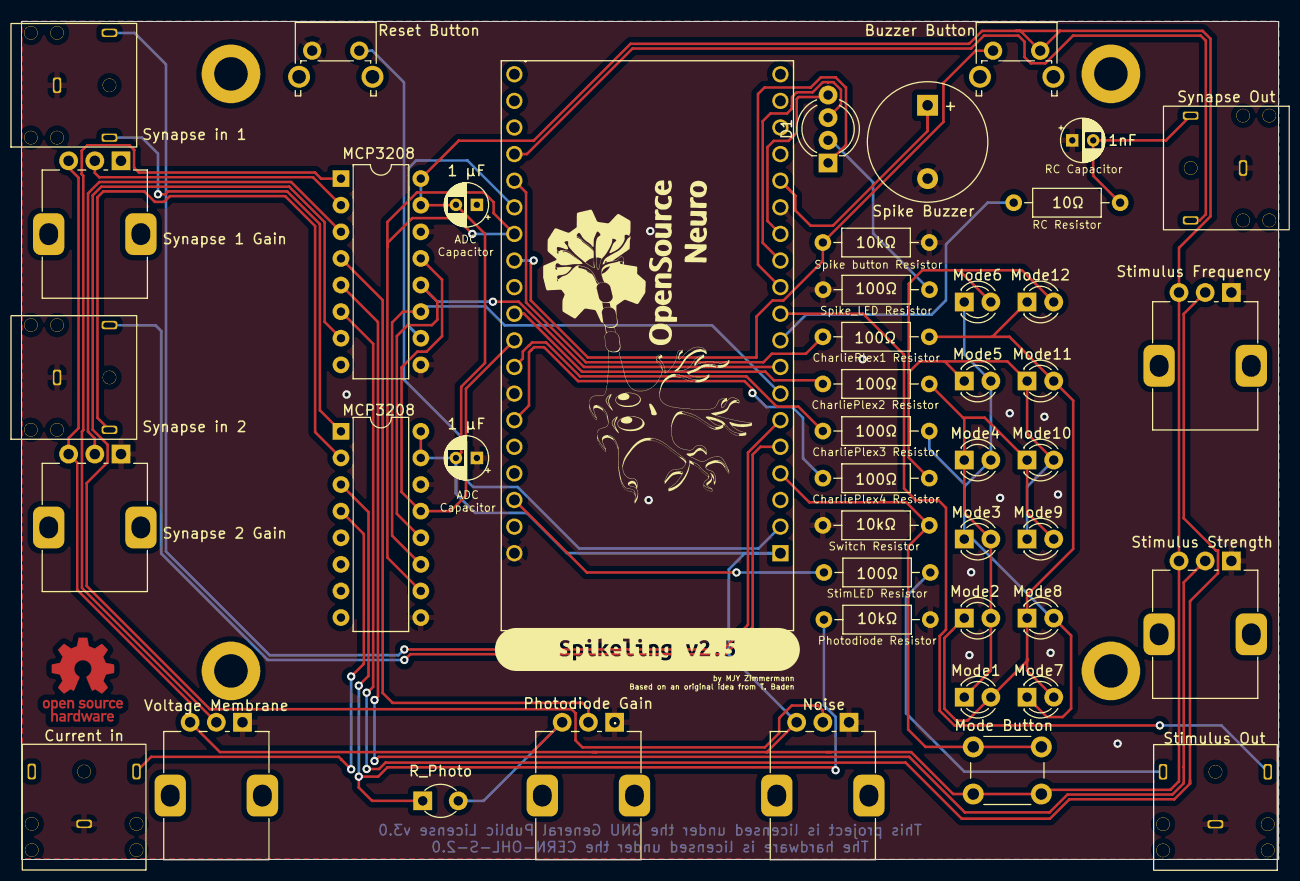
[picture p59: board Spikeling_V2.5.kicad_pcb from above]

Board: 2 copper layers, 120.0 x 80.0 mm, 53 parts (0 on the bottom side), 42 nets.

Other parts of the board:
 : MountingHole_3.2mm_M3_DIN965_Pad
 #2: MountingHole_M3; MountingHole_3.2mm_M3_DIN965_Pad
 #3,  #4: MountingHole_3.2mm_M3_DIN965_Pad
.: Spikeling_neuron; Spikeling_Photoreceptor
.#2: Spikeling_neuron; Spikeling_Neuron
kibuzzard-6957C1B9: G***; kibuzzard-6957C1B9

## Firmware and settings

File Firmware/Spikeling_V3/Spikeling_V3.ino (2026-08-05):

/* SPDX-License-Identifier: GPL-3.0-or-later */
/* ========================================================================================================

  Spikeling V3.0 – Main Firmware
  ---------------------------------------------------------------------------------------------------------

  Open-source, spiking neuron simulator running an Izhikevich-style model.
    Project      : Spikeling
    Repository   : https://github.com/OpenSourceNeuro/Spikeling
    File         : Spikeling_V3.ino
    Board        : ESP32-S3-WROOM-1
    Author       : Maxime Zimmermann
    License      : GPL-3.0-or-later (https://www.gnu.org/licenses/gpl-3.0.html)

  Libraries :
    - Arduino core for ESP32
    - MCP_ADC 
    - MCP_DAC
    - SerialCommand
    - Gaussian noise library

  Description  :
    This sketch configures the Spikeling hardware, runs the Izhikevich neuron model in real time, handles 
    all analog/digital IO (Vm, synapses, photodiode, stimulus, noise), and streams compact binary packets 
    to the host GUI for oscilloscope-style visualisation and control.

  Arduino IDE — Tools menu settings used for this build :
    Core / Board --------------------------------------------------------------
      Tools > Board:                 ESP32S3 Dev Module
      Tools > USB Mode:              Hardware CDC and JTAG (wording may vary)
      Tools > USB CDC On Boot:       Enabled

    CPU / Flash / PSRAM ------------------------------------------------------
      Tools > CPU Frequency:         240MHz 
      Tools > Flash Frequency:       80MHz 
      Tools > Flash Mode:            QIO 80MHz
      Tools > Flash Size:            4MB 
      Tools > PSRAM:                 Disabled 

  ---------------------------------------------------------------------------------------------------------
  (c) 2025 Maxime Zimmermann and contributors.
  This is free software; you can redistribute it and/or modify it under the terms of the GNU General Public
  License as published by the Free Software Foundation; 
  ====================================================================================================== */



// // // // // // // // // // // // // // // // // // // // // // // // // // // // // // // // // // // // 
/*                                        Header import                                                  */ 

  //#include "WiFi_functions.h"                                                          
  #include "Core_functions.h"
  #include "Serial_functions.h"


// // // // // // // // // // // // // // // // // // // // // // // // // // // // // // // // // // // // 
/*                                             Setup                                                     */ 

void setup() {
  HardwareSettings();                                                                           // Initialise all components
  calibrate_PhotodiodeDark();                                                                   // Set dark baseline with stim outputs forced OFF
  SerialFunctions();                                                                            // Initialise Serial commands
  //setupWifiAP();
  //Mode_opening();
}



// // // // // // // // // // // // // // // // // // // // // // // // // // // // // // // // // // // // 
/*                                          Main Loop                                                    */ 

void loop() {

  //wifiLoop();                                                                                   // Keep websocket responsive

  timing.current_us = micros();

  if ((timing.current_us - timing.lastStep_us) >= timing.step_us) {                             // It the time since the last loop has treached the set loop refresh rate
    timing.lastStep_us += timing.step_us;                                                       // keep steps evenly spaced

    SCmd.readSerial();                                                                          // Reads Serial for external commands
    
    poll_ToggleButtons();                                                                       // Read buzzer/LED toggle buttons (raw + time)
    update_ToggleButtons();                                                                     // Toggle buzzer/LED enable flags when pressed
    
    update_PatchInput();                                                                        // Sets Voltage membrane clamp value or inject Current      

    update_Noise();                                                                             // Sets Noise current level

    update_Photodiode();                                                                        // Sets Light generated current

    update_Synapse(syn1, syn1.defaultdecay);                                                    // Sets Synapse 1 current

    update_Synapse(syn2, syn2.defaultdecay);                                                    // Sets Synapse 2 current

    update_StimulusOutput();                                                                    // Determines Analog and Digital Values
    
    update_StimulusCurrentIn();                                                                 // Computes the dynamic Stimulus current 

    update_StimulusStatusLED();                                                                 // Mirror stimulus on RGB LED (intensity + polarity)

    update_VoltageClampPI();                                                                    // If in voltage-clamp mode, compute PI clamp current
                                                                 
    update_AllCurrent();                                                                        // Apply all current to the model



/*               -----  Spikeling computation running on Izhikevich mmodel  -----                        */

    neuron.v = neuron.v + neuron.dt_ms*(0.04 * neuron.v * neuron.v  + 5*neuron.v + 140 - neuron.u + neuron.total_current);   // Compute the voltage variable
    neuron.u = neuron.u + neuron.dt_ms*(neuron.a * (neuron.b * neuron.v - neuron.u));                                        // Compute the recovery variable

    if (clampMode != ClampMode::VoltageClamp){                                                  // If voltage clamp is off
      if (neuron.v >= neuron.Vm_peak){                                                            // If the membrane voltage has crossed the spike threshold (30mV by default):
        neuron.v = neuron.c;                                                                        // Reset membrane potential to the model’s reset value “c” (represents rapid repolarisation after an action potential).
        neuron.u = neuron.u + neuron.d;                                                             // Increase recovery/adaptation variable by “d” (represents spike-triggered adaptation / after-spike conductances).
      }
    }


/*                          -----  Voltage clamp numeric safety  -----                                   */

    if (clampMode == ClampMode::VoltageClamp) {
      if (!isfinite(neuron.v) || !isfinite(neuron.u)) {
        neuron.v = constrain(patch.v_cmd, neuron.Vm_min, neuron.Vm_peak);
        neuron.u = neuron.b * neuron.v;                                                         // Reinitialize recovery variable consistently
        patch.e_int   = 0.0f;                                                                   // Reset PI history (it will also be invalid)
        patch.I_clamp = 0.0f;
      }

      static uint8_t vc_clip_ctr = 0;
      if (neuron.v >= (neuron.Vm_peak - 1e-3f)) vc_clip_ctr++; else vc_clip_ctr = 0;

      if (vc_clip_ctr >= 3) {
        neuron.v = constrain(patch.v_cmd, neuron.Vm_min, neuron.Vm_peak - 1.0f);
        neuron.u = neuron.b * neuron.v;
        patch.e_int   = 0.0f;
        patch.I_clamp = 0.0f;
        vc_clip_ctr = 0;
      }      
      neuron.v = constrain(neuron.v, neuron.Vm_min, neuron.Vm_peak);                            // Hard-bound Vm so the quadratic term can never run away in V-clamp.
    }
    
    if (neuron.v <= neuron.Vm_min) {                                                            // If voltage goes below the min voltage value (-90mV by default):
      neuron.v = neuron.Vm_min;                                                                   // Keep the voltage at Vm_min : Prevent pinVm going into overdrive - but also means that it will flatline at Vm_min. 
    } 

    update_Spike();                                                                             // Handles spike related functions and hardware (LED + Buzzer) and generate Axon Digital and Analog output

    send_SamplePacket();                                                                        // Quantize the current state data and send it as a compact binary frame.
  }
}

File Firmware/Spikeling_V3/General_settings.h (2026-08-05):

#pragma once  

#include <cstdint>



// // // // // // // // // // // // // // // // // // // // // // // //
/*                         Librairies import                         */ 
                                                                      
#include "Izhikevich_parameters.h"
#include <Arduino.h>
#include <esp_system.h>
#include <SPI.h>
#include <MCP_ADC.h>                                        // Microchip SPI ADC Library by Rob Tillaart                 https://github.com/RobTillaart/MCP_ADC
#include <MCP_DAC.h>                                        // Microchip SPI DAC Library by Rob Tillaart                 https://github.com/RobTillaart/MCP_DAC
#include <Gaussian.h>                                       // Gaussian Library by Ivan Seidel                           https://github.com/ivanseidel/Gaussian
#include <SerialCommand.h>                                  // SerialCommand Library by Shyd (based on Steven Cogswell)  https://github.com/shyd/Arduino-SerialCommand



// // // // // // // // // // // // // // // // // // // // // // // //
/*                              Timing                               */

struct Timing {
  uint32_t current_us;
  uint32_t lastStep_us;
  uint32_t step_us;
};
inline Timing timing{
 .current_us  =  0,
 .lastStep_us =  0,
 .step_us     = 2000
};



// // // // // // // // // // // // // // // // // // // // // // // //
/*                        Serial parameters                          */

const float V_SCALE     = 100.0f;                           // 2 decimal places for voltages
const float I_SCALE     = 100.0f;                           // 2 decimal places for currents
const float SYN_V_SCALE = 100.0f;                           // 2 decimal places for voltages

struct SamplePacket {                                     // This struct must remain exactly 16 bytes (8 × int16_t), enforced by the static_assert below.
  int16_t v_q;                                              // v_out * V_SCALE -- v_q: int16_t, v_out in mV*0.01 => [-327.68, +327.67] V
  int16_t stim_state;                                       // Stim_State
  int16_t Itot_q;                                           // I_Total * I_SCALE
  int16_t syn1_vm_q;                                        // Syn1_Vm * SYN_V_SCALE
  int16_t Isyn1_q;                                          // I_Synapse1 * I_SCALE
  int16_t syn2_vm_q;                                        // Syn2_Vm * SYN_V_SCALE
  int16_t Isyn2_q;                                          // I_Synapse2 * I_SCALE
  int16_t trigger_q;                                        // Trigger
};

static_assert(sizeof(SamplePacket) == 16,"SamplePacket must remain 16 bytes (protocol compatibility)");



// // // // // // // // // // // // // // // // // // // // // // // //
/*                       Hardware parameters                         */

constexpr unsigned long BaudRate   = 500000;

constexpr int bits8      = 255;
constexpr int bits10     = 1023;
constexpr int bits12     = 4095;
constexpr int dac_bits   = 12;
constexpr uint16_t  dac_max    = 4095;
constexpr uint16_t stim_dac_zero = (dac_max + 1) / 2;        // 2048 = zero-current DAC code
constexpr uint16_t stim_dac_span = dac_max - stim_dac_zero;  // 2047 usable counts above/below zero
constexpr uint16_t current_in_rail_margin   = 80;  // ADC values near 0 or 4095 are not accepted as autozero
constexpr uint16_t current_in_stable_delta  = 8;   // Max ADC-count movement considered stable
constexpr uint16_t current_in_arm_samples   = 50;  // 50 loops × 2 ms = ~100 ms with your current timing
   
inline MCP3208 ADC1;                                        // First MCP3208 12-bit SPI ADC
inline MCP3208 ADC2;                                        // Second MCP3208 12-bit SPI ADC
inline MCP4922 DAC;                                         // MCP4922 12-bit SPI DAC
inline SamplePacket pkt;                                    // Reusable 16-byte sample packet buffer for streaming data over serial



// // // // // // // // // // // // // // // // // // // // // // // //
/*                           Potentiometer                           */
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

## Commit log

2025-08-31 update Arduino
2025-08-31 update PyQt
    [sine_50i_20Hz_200ms.csv, test.csv]
2025-11-20 update PCB
    [bom.csv, designators.csv]
2025-12-08 commit archives
    [1-click-bom.csv, 10i_500msON_500msOFF.csv, BoM.csv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]
2025-12-23 update GUI
    [sine_100i_1Hz_1000ms.csv]
2025-12-29 update Archives
    [1-click_BOM.tsv, Bill of Materials (BOM).xlsx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]
2026-01-02 update venv
    [pyvenv.cfg]
2026-01-02 update pcb 3.0
    [Spikeling_v3.0-B_Adhesive.gbr, Spikeling_v3.0-B_Courtyard.gbr, Spikeling_v3.0-B_Cu.gbr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]
2026-01-02 update pcb 2.5
    [1-click-bom.csv, BoM.csv, Spikeling_V2.4.kicad_pcb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]
2026-01-03 restructure software folder
    [10i_500msON_500msOFF.csv, 123 .csv, 123.csv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]
2026-01-03 update virtual environment for mkdocs
    [pyvenv.cfg]
2026-01-03 restructure archive folder
    [1-click-bom.csv, 1-click_BOM.tsv, 10i_500msON_500msOFF.csv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]
2026-01-03 restructure Firmware folder
    [cmn_crt_authorities.csv]
2026-01-03 update firmware folder
    [cmn_crt_authorities.csv]
2026-01-03 restructure hardware folder
    [BoM.csv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]
2026-02-17 update design
    [Spikeling-v3_Cover.dxf]
2026-02-23 create archive folder for Spikeling v3.1
    [Spikeling_v3.1-B_Adhesive.gbr, Spikeling_v3.1-B_Courtyard.gbr, Spikeling_v3.1-B_Cu.gbr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]
2026-02-23 declassify version 3.1
    [Spikeling_v3.1-B_Adhesive.gbr, Spikeling_v3.1-B_Courtyard.gbr, Spikeling_v3.1-B_Cu.gbr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]
2026-02-23 create version 3.2
    [Spikeling_v3.2-B_Adhesive.gbr, Spikeling_v3.2-B_Courtyard.gbr, Spikeling_v3.2-B_Cu.gbr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]
2026-03-06 update hardware
    [Spikeling_v3.2.kicad_pcb]
2026-03-10 update recording files
    [123 .csv, 123.csv, 123123123.csv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]
2026-03-13 update software tetrode view fix
    [Graph_ExtraCellular.py, Parameters_NavigationButtons.py, Tetrode.py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]
2026-03-13 update software tetrode rotation fixed
    [Page_ExtraCellular_Scope.py, Page_Spikeling_NeuronEmulator.py, Tetrode.py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]
2026-05-26 update arduino files v3
2026-07-14 update laser cut cover
    [Spikeling-v3_Cover.dxf, SpikelingV3_CoverFront_Cut.dwg, SpikelingV3_CoverFront_Cut.dxf]
2026-09-30 add graph_core.py, fix emulator reading ~30 UI widgets per simulation steps, so about 300000 calls per 50ms, now checks once per tick to respect the python QT clock boundary, more of a performance re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
    [Graph_Emulator.py, graph_core.py]
2026-09-30 cleanup, delete duplicates, cleaner piping/buffering, fix in apply GECI transposed keys silently swapping the indicator kinetics with the saturation amplitude, fix axis labels
    [Graph_Imaging.py]
2026-09-30 cleanup, delete duplicates, cleaner piping/buffering, per-sample sosfilt and per-sample geometry recomputation moved to block operations
2026-09-30 add connections of toggle buttons for noise, because the extracellular graph starts with noise although the buttons for noise are off
    [Graph_ExtraCellular.py, Page_ExtraCellular_Scope.py]
2026-10-01 cleanup constants, optimized sliders reading, better source switching, better recording gating
2026-10-01 channel 4 in extracellular graph had a smaller y axis due to the time x axis display, making the 4th trace look smaller in amplitude. Now all channels are scaled the same
2026-10-12 add spikeling_discovery.py to scan ports and automatically connect a detected Spikeling unit, add connection_supervisor.py to check if there is a disconnection and restart if if it comes back, integr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
2026-10-14 Fix board connection working on windows just after reseting the board.
2026-10-18 Filled settings page to control apprearance of the gui. Light/dark or custom mode, traces thickness, apply/reset buttons and import/export configuration buttons, with configurations that are conserve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
2026-10-18 modify build files to include the new setting page for appearance under the different platforms - bild button is back
2026-10-18 add github page with buttons to the repo, the releases, the report an issue tab, and buttons to check for a newer release and option to download the new release to replace the outdated one UNTESTED
2026-10-28 firmware: add passive voltage-clamp prototype and native regression tests
2026-10-29 firmware: prototype active HH voltage clamp with shared pharmacology and bench tests
2026-10-29 docs: record physical TTX and TEA voltage-clamp verification
2026-10-29 firmware: reuse the voltage exponential to improve active access timing margin
2026-10-30 docs: verify five physical VC handovers and close first integration stage
2026-10-30 Add two-Spikeling synaptic voltage-clamp test pack
    Keep the tested firmware unchanged. Add independent event-response and reversal references, drug protocols, native fault tests, serial workflow QA and Windows wiring instructions.
2026-10-30 Record physical Synapse 1 voltage-clamp PASS
    Independently verify the complete 21,670-sample capture and fast-current recurrence. Record evidence hashes, timing and cleanup scope; advance the next board action to basic Synapse 2 without changin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
2026-10-30 Record physical Synapse 2 voltage-clamp PASS
    Verify all 23,460 samples, timing, fast-current increments and CC cleanup. Record evidence hashes and both-input scope; advance the next board action to NBQX control/block/washout without changing fi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
2026-10-30 Retain first physical NBQX timing FAIL with verified drug response
    Record all 26,549 samples, half-block/washout, evidence hashes and the isolated 22.256 ms quiet-period overrun outside the HH solve. Preserve acceptance criteria and request one controlled repeat; do not label the run as an overall pass.
2026-10-30 Record complete physical NBQX repeat PASS
    Verify all 26,409 samples, half-block/washout, cadence and CC cleanup under unchanged criteria. Preserve the earlier timing FAIL and unresolved runtime pause; advance the next board case to gabazine.
2026-10-30 Record complete physical gabazine voltage-clamp PASS
    Verify all 24,230 samples, outward GABA-A polarity, half-block/washout, timing and CC cleanup. Preserve earlier timing failures and advance the next board action to AMPA reversal without changing firmware, tools or criteria.
2026-10-30 Record complete physical AMPA reversal PASS
    Verify all 25,591 samples, received-event driving-force scaling and reversal near 0 mV, timing and CC cleanup. Record a separate direct-increment fit and advance the next board case to GABA-A reversal without changing firmware or criteria.
2026-10-30 Record complete physical GABA-A reversal PASS
    Verify all 31,812 samples, event-resolved driving-force scaling and reversal near -80 mV, timing and CC cleanup. Preserve earlier timing observations and advance the next board action to NMDA/APV without changing firmware, tools or criteria.
2026-10-30 feat: add opt-in VC timing trace after repeated GVIA failures
2026-10-30 test: record clean traced GVIA capture and add extended observation
2026-10-30 fix: guard active VC USB writes after traced transmission stall
2026-11-01 STP+VC: provide host-only full-sketch STP state probe for regression tests
2026-11-01 STP+VC: full-sketch C++ integration tests for active/passive clamp, signed inputs, resets and handovers
2026-11-01 STP+VC: COM5 hardware battery for event multipliers, compensating currents and VC timing flags
2026-11-01 STP+VC: check full intrinsic-ionic current balance and float-precision model agreement
2026-11-01 STP+VC hardware: validate complete Kirchhoff current balance including active ionic currents
2026-11-01 STP+VC: supply complete VC current fields in synthetic failure-case fixtures
2026-11-01 STP+VC: correct VC1 newline escape for record-framed diagnostics
2026-11-01 STP+VC hardware: continuously drain serial through prompts and record only armed samples
2026-11-01 STP+PH: document single-event factorisation for current, AMPA/GABA and NMDA conductance
2026-11-01 STP+PH: expose shared event/release/receptor state in native-only test driver
2026-11-01 STP+PH: fix newline in native-only diagnostic state probe
2026-11-01 STP+PH: guarded COM5 active-VC hardware battery for deterministic current, AMPA, GABA and drugs
2026-11-01 STP+PH: add full waveform reconstruction for NMDA and APV in active voltage clamp
2026-11-01 STP+PH: independent NMDA biexponential synthetic traces and failure-detection regressions

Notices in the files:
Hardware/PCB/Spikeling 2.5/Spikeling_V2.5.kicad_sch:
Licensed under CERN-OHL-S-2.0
